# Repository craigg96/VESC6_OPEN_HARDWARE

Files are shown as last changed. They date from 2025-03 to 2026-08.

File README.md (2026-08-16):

# VESC6_OPEN_HARDWARE
Open source implementation of the vesc 6 hardware schematics published by Benjamin Vedder. Built in KiCAD and contains JLCPCB component IDs for everthing populated on the board so anyone can order their own!

## Design
* Continuous current: 70A; instantaneous current: 120A (With proper heat sinking)
* STL130N6F7 MOSFETs rated to switch up to 130A, software limits it to 120A.
* Voltage: 10V-60V(Cells: 3-13S)
* Ports: USB, CAN x2, ADC, on/off switch, SWD, Hall Sensors
* LSM6DS3 IMU
* JST-SH connectors (6pin and 4 pin)
* Holes either side of the MOSFETs allow for even clamping of a simple rectangular heatsink.

## Manufacture
* Economy PCBA maufacture can be used without placing the IMU - 5 boards approx £160GBP
* Standard PCBA manufacture with placing the IMU costs more - 5 boards approx £200GBP
* Custom board software build as well as hardware configuration files are available in the software folder.

## Testing so far...
Release 1 has been flashed and fully tested on the bench to verify current feedback, backEMF sensing, temperature sensing and IMU work as expected.
Hardware has been field tested by several months of daily use (ebike) pulling sustained power over 2kW with no issues.

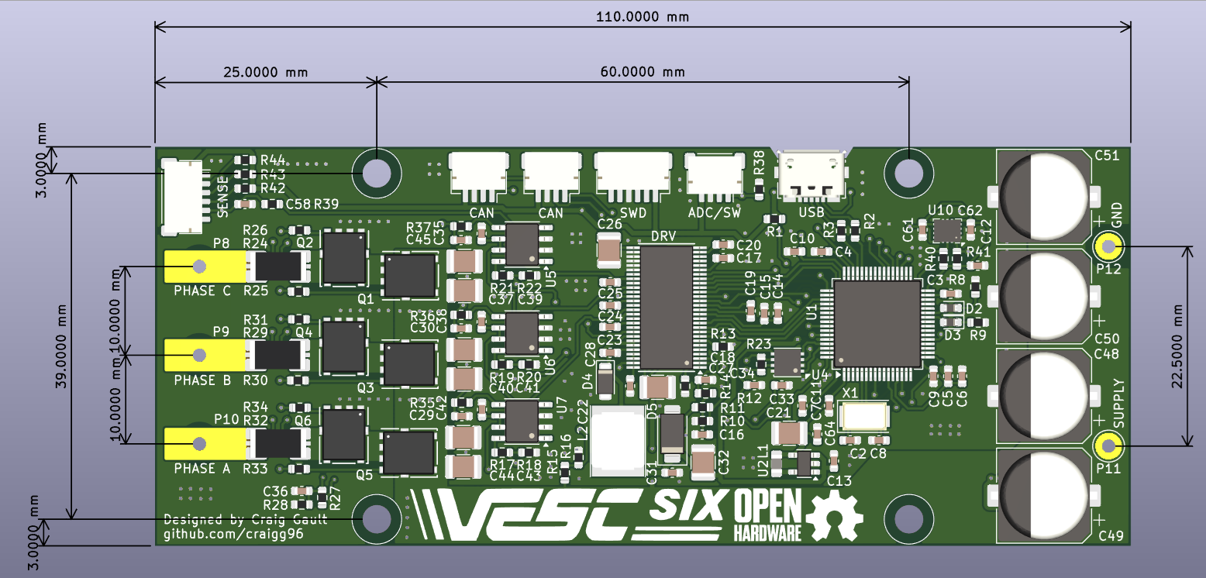
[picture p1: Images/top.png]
top

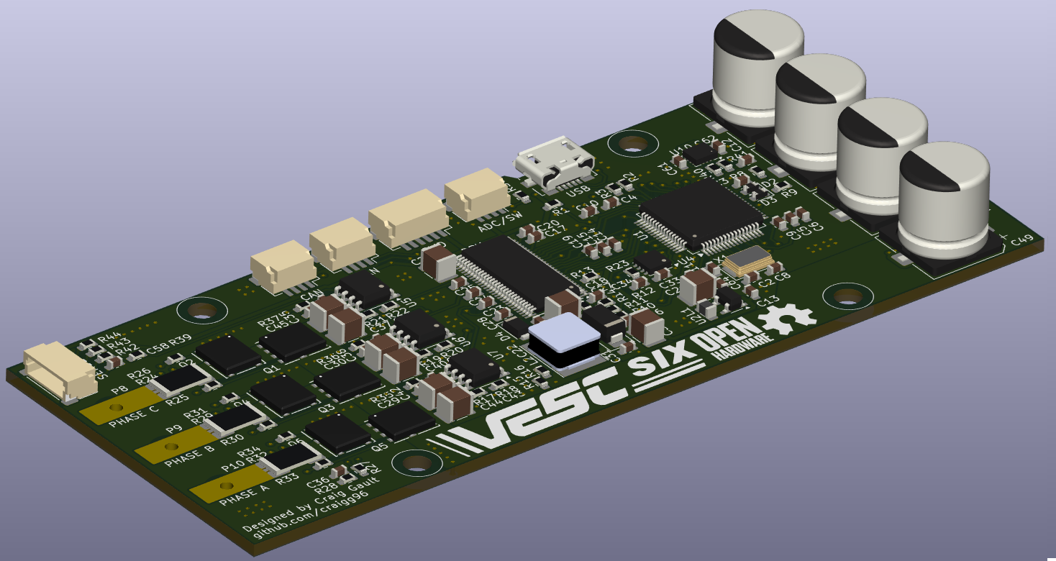
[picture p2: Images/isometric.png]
isometric

isometric

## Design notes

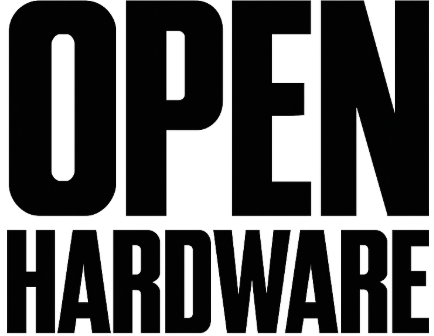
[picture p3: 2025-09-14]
Images/OH TEXT.png

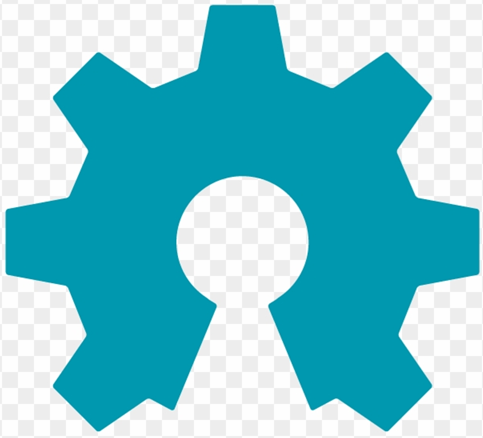
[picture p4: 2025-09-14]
Images/OH.png

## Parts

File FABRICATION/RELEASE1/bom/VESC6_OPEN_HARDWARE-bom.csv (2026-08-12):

Designator | JLCPCB Part # | Qty | Value
C2,C8 | C1644 | 2 | 15p
C3,C4,C5,C6,C9,C10,C11,C12,C13,C14,C15,C17,C20,C31,C33,C34,C35,C36,C38,C42,C64 | C23630 | 21 | 2.2uF
C7,C28,C58,C61,C62 | C14663 | 5 | 100n
C16 | C1631 | 1 | 6.8n
C18 | C107035 | 1 | 120p
C19 | C21122 | 1 | 22n
C21,C32 | C16133 | 2 | 100u
C22 | C1596 | 1 | 15n
C23,C24,C25 | C21120 | 3 | 220n
C26,C27,C37,C39,C40,C41,C43,C44 | C385987 | 8 | 4.7u_100v
C29,C30,C45 | C53987 | 3 | 4.7n
C48,C49,C50,C51 | C7471900 | 4 | 220u_63v
D2 | C2286 | 1 | RED
D3 | C2290 | 1 | WHITE
D4 | C2923951 | 1 | DIODE
D5 | C129544 | 1 | TVS 5V
H1,H2,H3,H4 |  | 4 | MountingHole
L1 | C383398 | 1 | 2.2u
L2 | C266430 | 1 | 22u
P1 | C132560 | 1 | USB_OTG
P2,P5,P6 | C23390337 | 1 | 4PINCONN
P3,P4 | C160405 | 1 | 6PINCONN
P8 |  | 1 | PH_C
P9 |  | 1 | PH_B
P10 |  | 1 | PH_A
P11 |  | 1 | SUPPLY
P12 |  | 1 | GND
Q1,Q2,Q3,Q4,Q5,Q6 | C501008 | 6 | STL130N6F7
R1,R38 |  | 1 | DNP
R2,R3 | C23345 | 2 | 22R
R8,R9,R23 | C22787 | 3 | 120R
R10 | C22978 | 1 | 3.3k
R11 | C25810 | 1 | 18k
R12 | C22809 | 1 | 15k
R13,R28,R39 | C25804 | 4 | 10k
R14 | C22961 | 1 | 220k
R15,R17,R19,R21 | C23153 | 4 | 39k
R16,R18,R20,R22,R42,R43,R44 | C4190 | 7 | 2k2
R24,R29,R32 | C469426 | 3 | 0.0005R
R25,R26,R30,R31,R33,R34 | C23164 | 6 | 4.7R
R27 | C76589 | 1 | NTC 10k
R35,R36,R37 | C22775 | 3 | 100R
R40,R41 | C21190 | 2 | 1k
U1 | C15742 | 1 | STM32F40X_LQFP64
U2 | C477918 | 1 | LM3671
U3 | C98969 | 1 | DRV8301
U4 | C124020 | 1 | TJA1051TK-3
U5,U6,U7 | C495342 | 3 | AD8418
U10 | C967633 | 1 | LSM6DS3TR-C
X1 | C115962 | 1 | 8m

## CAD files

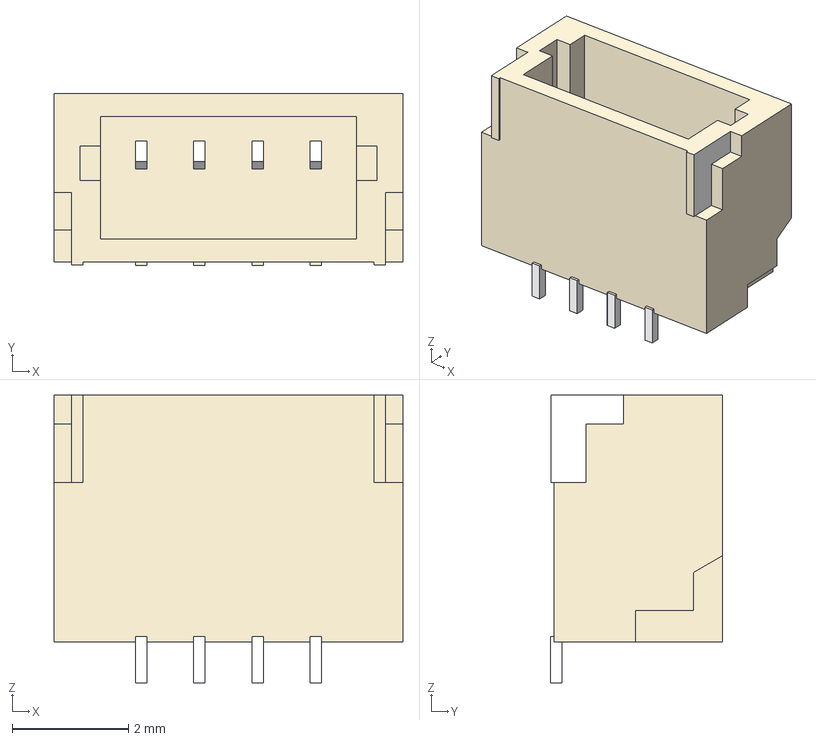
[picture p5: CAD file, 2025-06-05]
3D/SM04B-SRSS-TB.STEP
6.00 x 2.96 x 4.95 mm

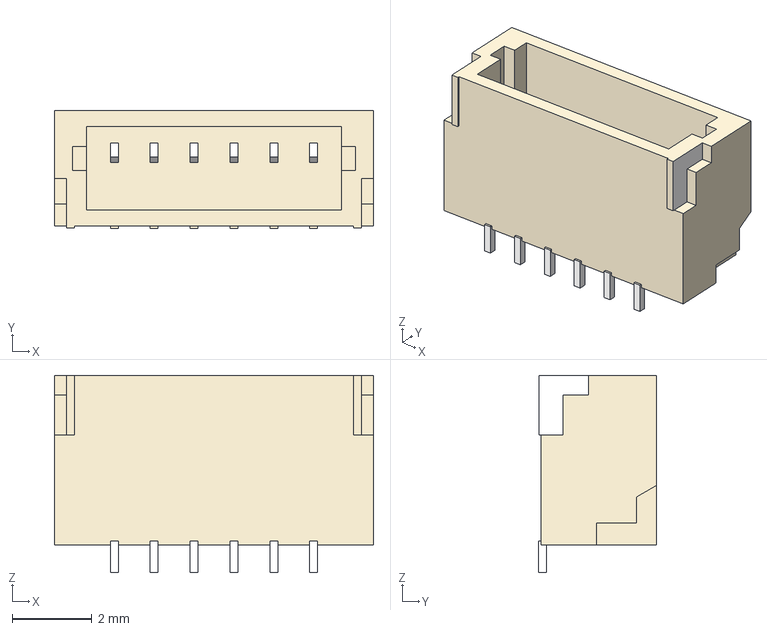
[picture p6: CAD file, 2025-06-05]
3D/SM06B-SRSS-TB.STEP
8.00 x 2.96 x 4.95 mm

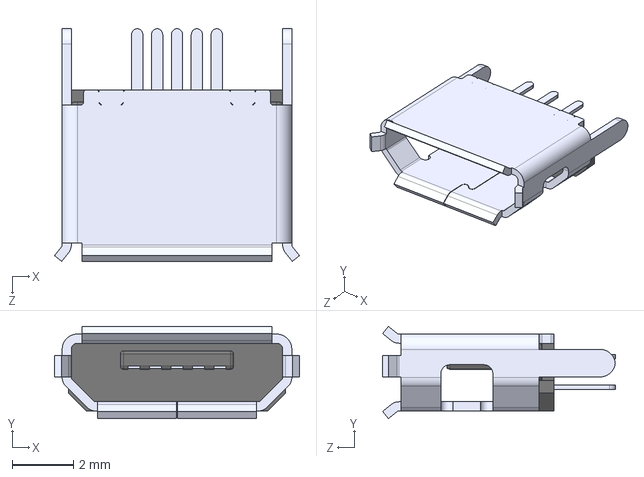
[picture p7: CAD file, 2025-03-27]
3D/USB-F.STEP
8.00 x 3.01 x 7.60 mm

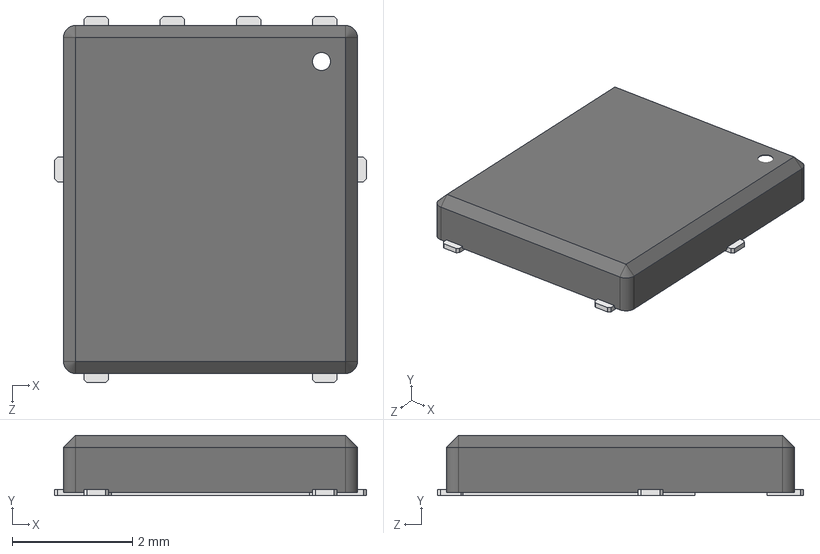
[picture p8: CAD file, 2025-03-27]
3D/SO-8FL.STEP
5.20 x 1.00 x 6.10 mm

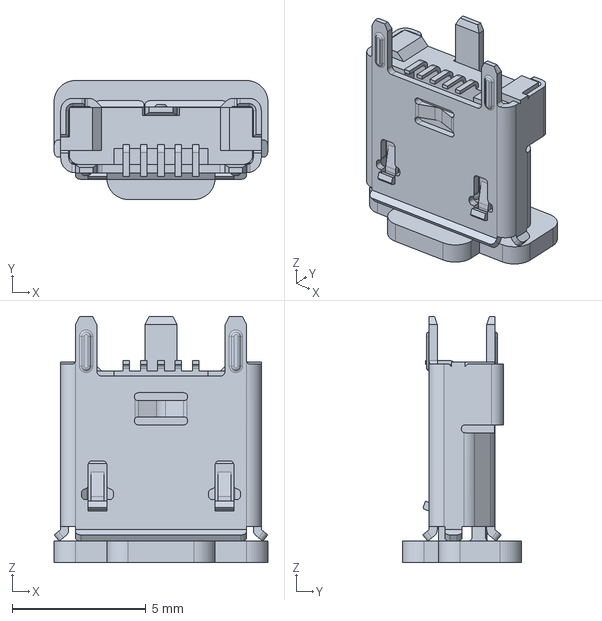
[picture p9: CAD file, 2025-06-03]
3D/1051330001.stp
8.00 x 4.45 x 9.20 mm

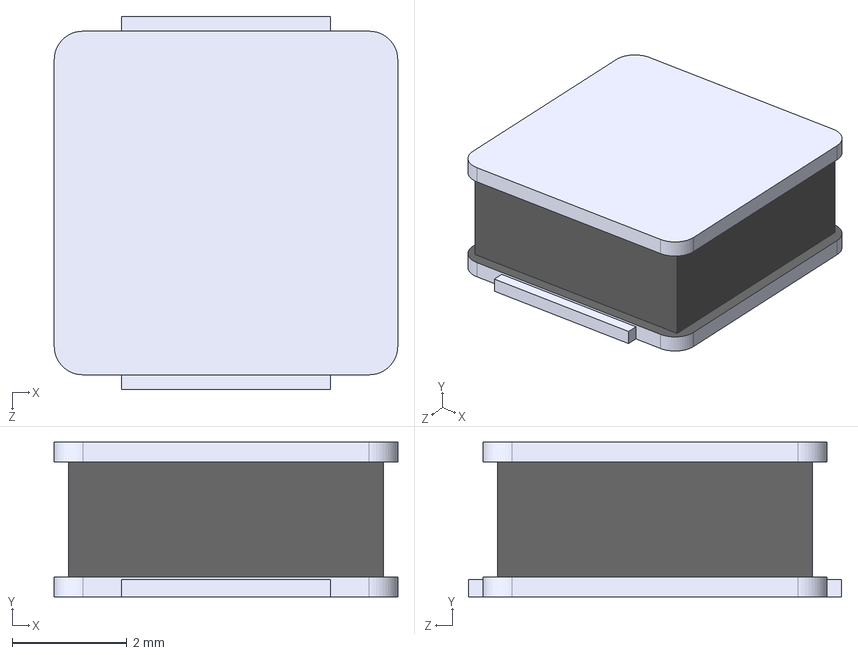
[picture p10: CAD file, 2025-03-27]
3D/C266430_220_inductor.STEP
6.00 x 2.70 x 6.51 mm

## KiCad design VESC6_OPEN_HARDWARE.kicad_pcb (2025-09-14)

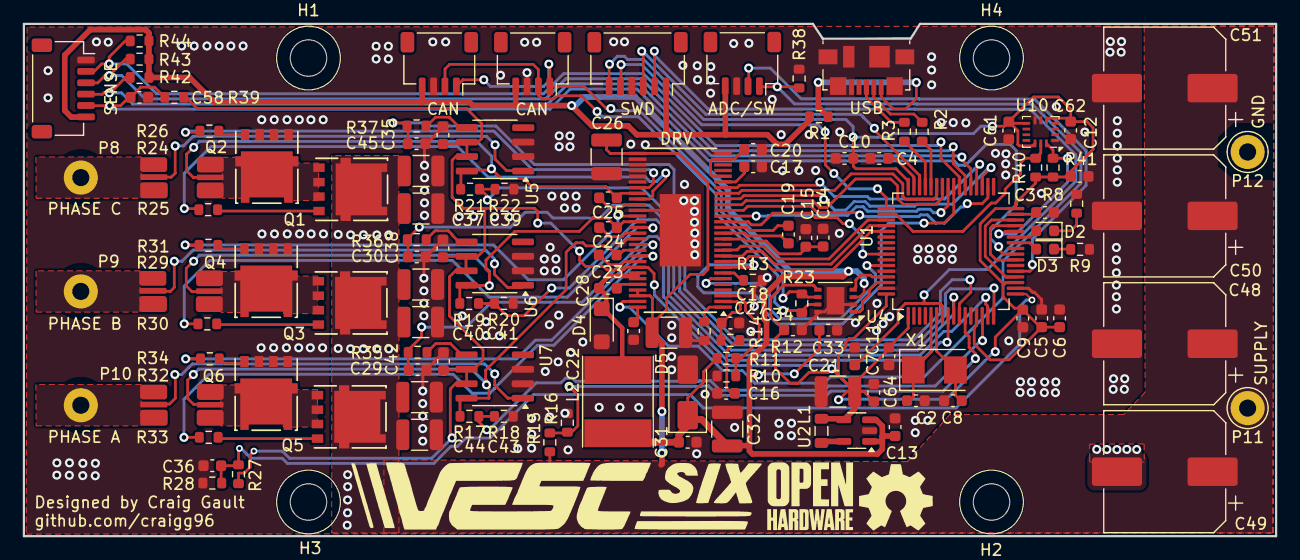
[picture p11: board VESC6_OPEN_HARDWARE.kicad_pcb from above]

Board: 4 copper layers, 110.0 x 45.0 mm, 128 parts (0 on the bottom side), 92 nets.

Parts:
ADC/SW: ADC_SWITCH; JST_SH_SM04B-SRSS-TB_1x04-1MP_P1.00mm_Horizontal
C2, C8: 15p; C_0603_1608Metric
C3, C4, C5, C6, C9, C10, C11, C12, C13, C14, C15, C17, C20, C31, C33, C34, C35, C36, C38, C42, C64: 2.2uF; C_0603_1608Metric
C7, C28, C58, C61, C62: 100n; C_0603_1608Metric
C16: 6.8n; C_0603_1608Metric
C18: 120p; C_0603_1608Metric
C19: 22n; C_0603_1608Metric
C21, C32: 100u; C_1210_3225Metric
C22: 15n; C_0603_1608Metric
C23, C24, C25: 220n; C_0603_1608Metric
C26, C27, C37, C39, C40, C41, C43, C44: 4.7u_100v; C_1210_3225Metric
C29, C30, C45: 4.7n; C_0603_1608Metric
C48, C49, C50, C51: 220u_63v; CP_Elec_10x10.5
CAN: CAN1; JST_SH_SM04B-SRSS-TB_1x04-1MP_P1.00mm_Horizontal
CAN#2: CAN2; JST_SH_SM04B-SRSS-TB_1x04-1MP_P1.00mm_Horizontal
D2: RED; D_0603_1608Metric
D3: WHITE; D_0603_1608Metric
D4: DIODE; D_SMF
D5: TVS 5V; D_SMA
H1, H2, H3, H4: MountingHole; MountingHole_3mm
L1: 2.2u; L_0805_2012Metric
L2: 22u; L_Taiyo-Yuden_NR-60xx_HandSoldering
P8: PH_C; Pin_D1.3mm_L11.0mm_LooseFit
P9: PH_B; Pin_D1.3mm_L11.0mm_LooseFit
P10: PH_A; Pin_D1.3mm_L11.0mm_LooseFit
P11: SUPPLY; Pin_D1.3mm_L11.0mm_LooseFit
P12: GND; Pin_D1.3mm_L11.0mm_LooseFit
Q1, Q2, Q3, Q4, Q5, Q6: STL130N6F7; NVMFS5C612NL
R1: DNP; R_0603_1608Metric
R2, R3: 22R; R_0603_1608Metric
R8, R9, R23: 120R; R_0603_1608Metric
R10: 3.3k; R_0603_1608Metric
R11: 18k; R_0603_1608Metric
R12: 15k; R_0603_1608Metric
R13, R28, R38, R39: 10k; R_0603_1608Metric
R14: 220k; R_0603_1608Metric
R15, R17, R19, R21: 39k; R_0603_1608Metric
R16, R18, R20, R22, R42, R43, R44: 2k2; R_0603_1608Metric
R24, R29, R32: 0.0005R; 2512_SHUNT
R25, R26, R30, R31, R33, R34: 4.7R; R_0603_1608Metric
R27: NTC 10k; R_0603_1608Metric
R35, R36, R37: 100R; R_0603_1608Metric
R40, R41: 1k; R_0603_1608Metric
SENSE: HALL/Encoder; JST_SH_SM06B-SRSS-TB_1x06-1MP_P1.00mm_Horizontal
SWD: SWD; JST_SH_SM06B-SRSS-TB_1x06-1MP_P1.00mm_Horizontal
U1: STM32F40X_LQFP64; LQFP-64_10x10mm_P0.5mm
U2: LM3671; SOT-23-5
U3: DRV8301; HTSSOP-56-1EP_6.1x14mm_P0.5mm_EP3.61x6.35mm
U4: TJA1051TK-3; DFN-8-1EP_3x3mm_P0.65mm_EP1.55x2.4mm
U5, U6, U7: AD8418; SOIC-8_3.9x4.9mm_P1.27mm
U10: LSM6DS3TR-C; Bosch_LGA-14_3x2.5mm_P0.5mm
USB: USB_OTG; USB_Micro-B_Molex_47346-0001
X1: 8m; Crystal_SMD_5032-2Pin_5.0x3.2mm

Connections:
+5V: ADC/SW.4, C13.1, C31.1, C32.1, C33.1, CAN.4, CAN#2.4, D5.1 (K), L2.2, R1.1, R11.2, R42.2, R43.2, R44.2, SENSE.6, SWD.1, U2.1 (Vin), U2.3 (EN), U4.3 (VCC)
/CAN/CANH: CAN.2, CAN#2.2, R23.1, U4.7 (CANH)
/CAN/CANL: CAN.1, CAN#2.1, R23.2, U4.6 (CANL)
/CAN/RX: U1.61 (PB8), U4.4 (RXD)
/CAN/TX: U1.62 (PB9), U4.1 (TXD)
/DRV8301/CS: U1.40 (PC9), U3.8 (M_PWM)
/DRV8301/EN_GATE: U1.57 (PB5), U3.16 (EN_GATE)
/DRV8301/FAULT: U1.59 (PB7), U3.6 (FAULT)
/DRV8301/GH_A: R33.2, U3.47 (GH_A)
/DRV8301/GH_B: R30.2, U3.42 (GH_B)
/DRV8301/GH_C: R25.2, U3.37 (GH_C)
/DRV8301/GL_A: R34.2, U3.45 (GL_A)
/DRV8301/GL_B: R31.2, U3.40 (GL_B)
/DRV8301/GL_C: R26.2, U3.35 (GL_C)
/DRV8301/INH_A: U1.41 (PA8), U3.17 (INH_A)
/DRV8301/INH_B: U1.42 (PA9(OTG_FS_VBUS)), U3.19 (INH_B)
/DRV8301/INH_C: U1.43 (PA10), U3.21 (INH_C)
/DRV8301/INL_A: U1.34 (PB13(OTG_HS_VBUS)), U3.18 (INL_A)
/DRV8301/INL_B: U1.35 (PB14), U3.20 (INL_B)
/DRV8301/INL_C: U1.36 (PB15), U3.22 (INL_C)
/DRV8301/SCLK: U1.51 (PC10), U3.11 (OC_ADJ)
/DRV8301/SDI: U1.53 (PC12), U3.9 (M_OC)
/DRV8301/SDO: U1.52 (PC11), U3.10 (GAIN)
/DRV8301/SENS_A: R17.2, R18.2, U1.14 (PA0(ADC123_IN0/WKUP))
/DRV8301/SENS_B: R19.2, R20.2, U1.15 (PA1(ADC123_IN1))
/DRV8301/SENS_C: R21.2, R22.2, U1.16 (PA2(ADC123_IN2))
/DRV8301/SENS_SUPPLY: R15.2, R16.2, U1.11 (PC3(ADC123_IN13))
/DRV8301/SH_A: C23.1, Q5.3 (S), Q6.1 (D), R17.1, R32.1, U3.46 (SH_A), U7.8 (IN+)
/DRV8301/SH_B: C24.1, Q3.3 (S), Q4.1 (D), R19.1, R29.1, U3.41 (SH_B), U6.8 (IN+)
/DRV8301/SH_C: C25.1, Q1.3 (S), Q2.1 (D), R21.1, R24.1, U3.36 (SH_C), U5.8 (IN+)
/DRV8301/SWITCH-: ADC/SW.1, R38.1, U3.55 (EN_BUCK)
/IMU/SCL: R40.2, U1.50 (PA15(JTDI)), U10.13 (SCX)
/IMU/SDA: R41.1, U1.28 (PB2-BOOT1), U10.14 (SDX)
/power/CURR_A: C29.1, R35.2, U1.8 (PC0(ADC123_IN10))
/power/CURR_B: C30.1, R36.2, U1.9 (PC1(ADC123_IN11))
/power/CURR_C: C45.1, R37.2, U1.10 (PC2(ADC123_IN12))
/power/C_A: R35.1, U7.5 (OUT)
/power/C_B: R36.1, U6.5 (OUT)
/power/C_C: R37.1, U5.5 (OUT)
/power/TEMP: C36.1, R27.2, R28.1, U1.17 (PA3(ADC123_IN3))
/stm32f40x/HALL_1: R42.1, SENSE.4, U1.37 (PC6)
/stm32f40x/HALL_2: R43.1, SENSE.3, U1.38 (PC7)
/stm32f40x/HALL_3: R44.1, SENSE.2, U1.39 (PC8)
/stm32f40x/LED_GREEN: D3.2 (A), U1.26 (PB0(ADC12_IN8))
/stm32f40x/LED_RED: D2.2 (A), U1.27 (PB1(ADC12_IN9))
/stm32f40x/NRST: C7.1, SWD.2, U1.7 (NRST)
/stm32f40x/RX_SDA_NSS: U1.20 (PA4(ADC12_IN4/DAC1_OUT)), U1.30 (PB11)
/stm32f40x/SCK_ADC_EXT: ADC/SW.2, U1.21 (PA5(ADC12_IN5/DAC2_OUT))
/stm32f40x/SWCLK: SWD.5, U1.49 (PA14(JTCK-SWCLK))
/stm32f40x/SWDIO: SWD.3, U1.46 (PA13(JTMS-SWDIO))
/stm32f40x/TEMP_MOTOR: C58.2, R39.2, SENSE.5, U1.24 (PC4(ADC12_IN14))
/stm32f40x/TX_SCL_MOSI: U1.23 (PA7(ADC12_IN7)), U1.29 (PB10)
/stm32f40x/USB_DM: R2.1, U1.44 (PA11)
/stm32f40x/USB_DP: R3.1, U1.45 (PA12)
GND: ADC/SW.3, C2.1, C3.1, C4.1, C5.2, C6.2, C7.2, C8.1, C9.2, C10.2, C11.2, C12.2, C13.2, C14.2, C15.2, C16.1, C17.2, C18.1, C20.2, C21.2, C22.2, C26.2, C27.2, C29.2, C30.2, C31.2, C32.2, C33.2, C34.2, C35.2, C36.2, C37.2, C38.2, C39.2, C40.2, C41.2, C42.2, C43.2, C44.2, C45.2, C48.2, C49.2, C50.2, C51.2, C58.1, C61.1, C62.1, C64.2, CAN.3, CAN#2.3, D4.2 (A), D5.2 (A), P12.1, Q2.3 (S), Q4.3 (S), Q6.3 (S), R8.2, R9.2, R10.1, R13.2, R14.1, R16.1, R18.1, R20.1, R22.1, R28.2, R38.2, SENSE.1, SWD.4, U1.12 (VSSA), U1.18 (VSS), U1.60 (BOOT0(VPP)), U1.63 (VSS), U2.2 (GND), U3.28 (AGND), U3.30 (SP2), U3.31 (SN2), U3.32 (SP1), U3.33 (SN1), U3.34 (SL_C), U3.39 (SL_B), U3.44 (SL_A), U3.57 (GND(POWER_PAD)), U4.2 (GND), U4.8 (S), U4.9 (GND), U5.2 (GND), U5.3 (REF2), U6.2 (GND), U6.3 (REF2), U7.2 (GND), U7.3 (REF2), U10.1 (SDO), U10.6 (GNDIO), U10.7 (GND), USB.5 (GND), USB.6 (Shield)
unnamed: C16.2, R12.1
unnamed: D2.1 (K), R8.1
unnamed: D3.1 (K), R9.1
unnamed: C28.1, D4.1 (K), L2.1, U3.50 (PH), U3.51 (PH)
unnamed: R3.2, USB.3 (D+)
unnamed: R2.2, USB.2 (D-)
unnamed: R1.2, USB.1 (VBUS)
unnamed: P8.1, R24.2, U5.1 (IN-)
unnamed: P9.1, R29.2, U6.1 (IN-)
unnamed: P10.1, R32.2, U7.1 (IN-)
unnamed: Q1.2 (G), R25.1
unnamed: Q2.2 (G), R26.1
unnamed: Q3.2 (G), R30.1
unnamed: Q4.2 (G), R31.1
unnamed: Q5.2 (G), R33.1
unnamed: Q6.2 (G), R34.1
unnamed: C2.2, U1.5 (PH0-OSC_IN), X1.1
unnamed: C8.2, U1.6 (PH1-OSC_OUT), X1.2
unnamed: C3.2, U1.31 (VCAP1)
unnamed: C4.2, U1.47 (VCAP2)
unnamed: L1.1, U2.5 (SW)
unnamed: C20.1, U3.24 (REF), U3.27 (AVDD)
unnamed: C23.2, U3.48 (BST_A)
unnamed: C24.2, U3.43 (BST_B)
unnamed: C28.2, U3.52 (BST_BK)
unnamed: C25.2, U3.38 (BST_C)
unnamed: C18.2, R12.2, U3.2 (COMP)
unnamed: C19.1, U3.14 (CP1)
unnamed: C19.2, U3.15 (CP2)
unnamed: R13.1, U3.7 (DTC)
unnamed: C17.1, U3.23 (DVDD)
unnamed: C14.1, C15.1, U3.13 (GVDD)
unnamed: R14.2, U3.1 (RT_CLK)
unnamed: C22.1, U3.56 (SS_TR)
unnamed: R10.2, R11.1, U3.3 (VSENSE)
SUPPLY: C26.1, C27.1, C37.1, C39.1, C40.1, C41.1, C43.1, C44.1, C48.1, C49.1, C50.1, C51.1, P11.1, Q1.1 (D), Q3.1 (D), Q5.1 (D), R15.1, U3.29 (PVDD1), U3.53 (PVDD2), U3.54 (PVDD2)
VCC: C5.1, C6.1, C9.1, C10.1, C11.1, C12.1, C21.1, C34.1, C35.1, C38.1, C42.1, C61.2, C62.2, C64.1, L1.2, R27.1, R39.1, R40.1, R41.2, SWD.6, U1.1 (VBAT), U1.13 (VDDA), U1.19 (VDD), U1.32 (VDD), U1.48 (VDD), U1.64 (VDD), U2.4 (FB), U3.49 (BIAS), U4.5 (VIO), U5.6 (VS), U5.7 (REF1), U6.6 (VS), U6.7 (REF1), U7.6 (VS), U7.7 (REF1), U10.5 (VDDIO), U10.8 (VDD), U10.12 (CSB)

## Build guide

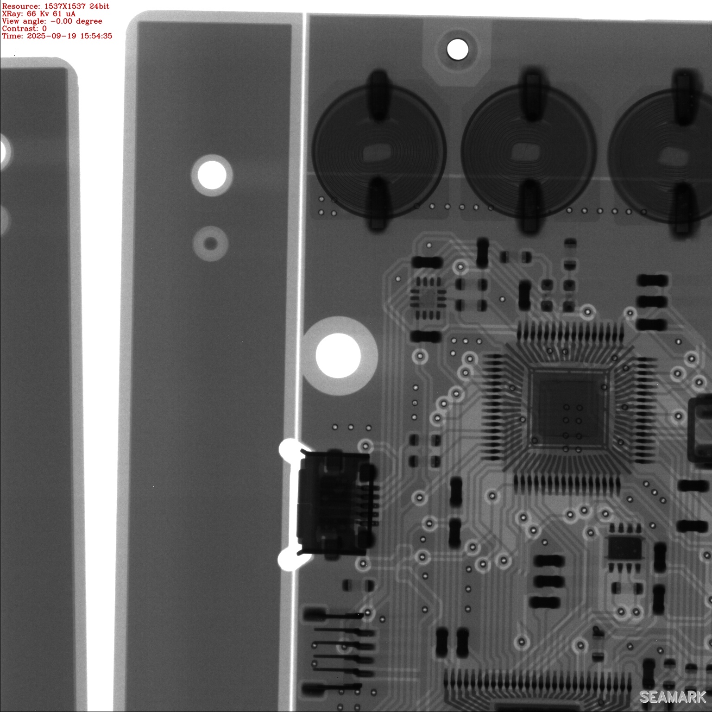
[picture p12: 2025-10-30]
FABRICATION/RELEASE1/x-ray inspection/4.jpg

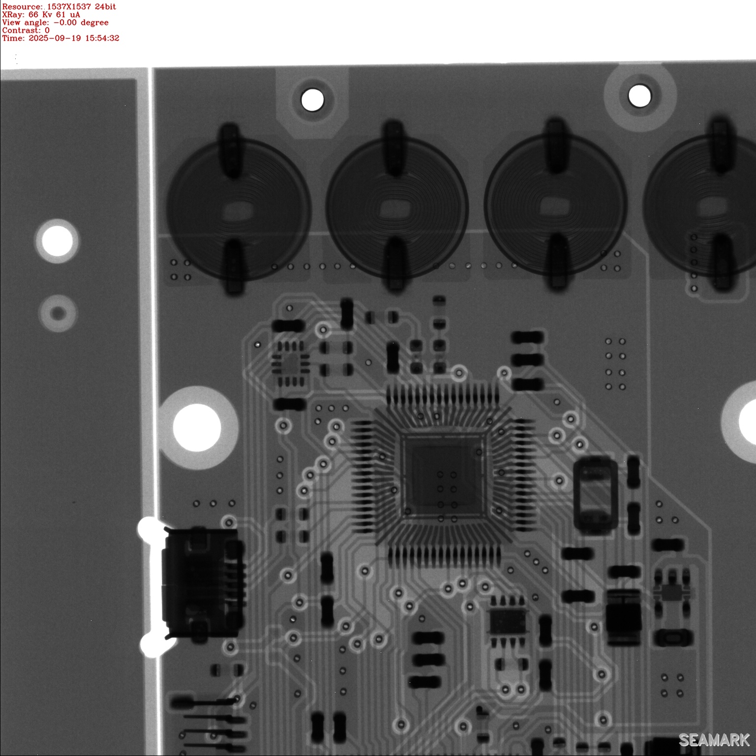
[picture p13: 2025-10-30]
FABRICATION/RELEASE1/x-ray inspection/3.jpg

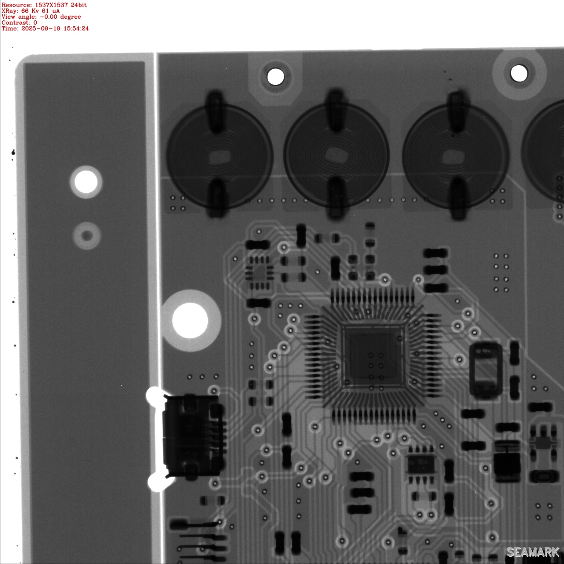
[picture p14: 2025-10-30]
FABRICATION/RELEASE1/x-ray inspection/1.jpg

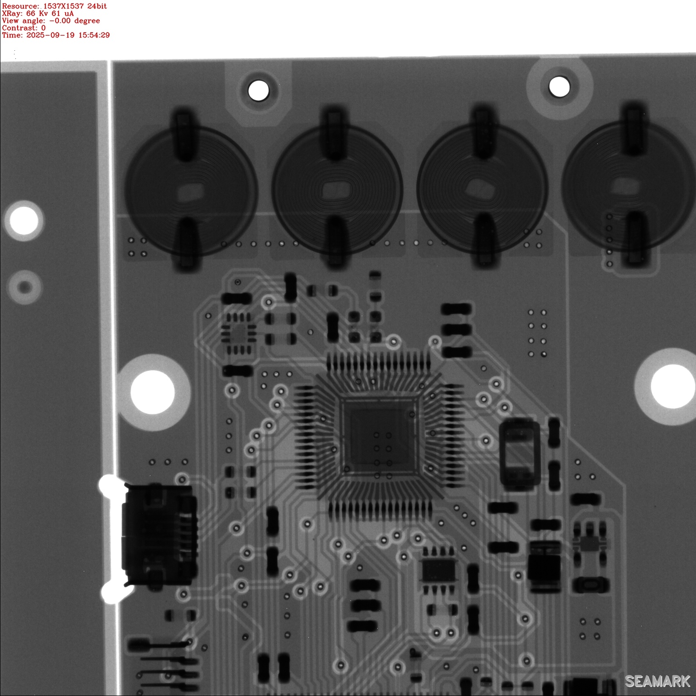
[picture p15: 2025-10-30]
FABRICATION/RELEASE1/x-ray inspection/2.jpg

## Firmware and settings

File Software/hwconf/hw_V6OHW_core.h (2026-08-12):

/*
	Copyright 2016 - 2026 Benjamin Vedder	benjamin@vedder.se

	This file is part of the VESC firmware.

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
    You should have received a copy of the GNU General Public License
    along with this program.  If not, see <http://www.gnu.org/licenses/>.
    */

#ifndef HW_V6OHW_CORE_H_
#define HW_V6OHW_CORE_H_

#ifdef HW_V6OHW_IS_MK1
#define HW_NAME                 "V6OHW"
#else
#error "Must include hardware type"
#endif

#define HW_MAJOR                1
#define HW_MINOR                0

// HW properties
#define HW_HAS_DRV8301
#define HW_HAS_3_SHUNTS
#define HW_HAS_PHASE_SHUNTS
#define HW_HAS_PERMANENT_NRF

// Macros
#define ENABLE_GATE()          palSetPad(GPIOB, 5)
#define DISABLE_GATE()         palClearPad(GPIOB, 5)
#define DCCAL_ON()
#define DCCAL_OFF()
#define IS_DRV_FAULT()         (!palReadPad(GPIOB, 7))

#define LED_GREEN_ON()         palSetPad(GPIOB, 0)
#define LED_GREEN_OFF()        palClearPad(GPIOB, 0)
#define LED_RED_ON()           palSetPad(GPIOB, 1)
#define LED_RED_OFF()          palClearPad(GPIOB, 1)

#define CURRENT_FILTER_ON()    palSetPad(GPIOD, 2)
#define CURRENT_FILTER_OFF()   palClearPad(GPIOD, 2)

// Component parameters
#ifndef V_REG
#define V_REG                  3.3
#endif
#ifndef VIN_R1
#define VIN_R1                 39000.0
#endif
#ifndef VIN_R2
#define VIN_R2                 2200.0
#endif
#ifndef CURRENT_AMP_GAIN
#define CURRENT_AMP_GAIN       20.0
#endif
#ifndef CURRENT_SHUNT_RES
#define CURRENT_SHUNT_RES      0.0005
#endif

// Voltage and temperature macros
#define GET_INPUT_VOLTAGE()    ((V_REG / 4095.0) * (float)ADC_Value[ADC_IND_VIN_SENS] * ((VIN_R1 + VIN_R2) / VIN_R2))
#define NTC_RES(adc_val)       ((4095.0 * 10000.0) / adc_val - 10000.0)
#define NTC_TEMP(adc_ind)      (1.0 / ((logf(NTC_RES(ADC_Value[adc_ind]) / 10000.0) / 3380.0) + (1.0 / 298.15)) - 273.15)
#define NTC_RES_MOTOR(adc_val) (10000.0 / ((4095.0 / (float)adc_val) - 1.0))
#define NTC_TEMP_MOTOR(beta)   (1.0 / ((logf(NTC_RES_MOTOR(ADC_Value[ADC_IND_TEMP_MOTOR]) / 10000.0) / beta) + (1.0 / 298.15)) - 273.15)
#define ADC_VOLTS(ch)          ((float)ADC_Value[ch] / 4096.0 * V_REG)

// Double samples configuration
#ifndef CURR1_DOUBLE_SAMPLE
#define CURR1_DOUBLE_SAMPLE    0
#endif
#ifndef CURR2_DOUBLE_SAMPLE
#define CURR2_DOUBLE_SAMPLE    0
#endif
#ifndef CURR3_DOUBLE_SAMPLE
#define CURR3_DOUBLE_SAMPLE    0
#endif

// ADC Vector
#define HW_ADC_INJ_CHANNELS    3
#define HW_ADC_NBR_CONV        5
#define HW_ADC_CHANNELS        (HW_ADC_NBR_CONV * 3)

// ADC Indexes
#define ADC_IND_SENS1          3
#define ADC_IND_SENS2          4
#define ADC_IND_SENS3          5
#define ADC_IND_CURR1          0
#define ADC_IND_CURR2          1
#define ADC_IND_CURR3          2
#define ADC_IND_VIN_SENS       11
#define ADC_IND_EXT            6
#define ADC_IND_EXT2           7
#define ADC_IND_TEMP_MOS       8
#define ADC_IND_TEMP_MOTOR     9
#define ADC_IND_VREFINT        12

// COMM-port ADC GPIOs
#define HW_ADC_EXT_GPIO        GPIOA
#define HW_ADC_EXT_PIN         5
#define HW_ADC_EXT2_GPIO       GPIOA
#define HW_ADC_EXT2_PIN        6

// UART Peripheral
#define HW_UART_DEV            SD3
#define HW_UART_GPIO_AF        GPIO_AF_USART3
#define HW_UART_TX_PORT        GPIOB
#define HW_UART_TX_PIN         10
#define HW_UART_RX_PORT        GPIOB
#define HW_UART_RX_PIN         11

// ICU Peripheral for servo decoding
#define HW_USE_SERVO_TIM4
#define HW_ICU_TIMER           TIM4
#define HW_ICU_TIM_CLK_EN()    RCC_APB1PeriphClockCmd(RCC_APB1Periph_TIM4, ENABLE)
#define HW_ICU_DEV             ICUD4
#define HW_ICU_CHANNEL         ICU_CHANNEL_1
#define HW_ICU_GPIO_AF         GPIO_AF_TIM4
#define HW_ICU_GPIO            GPIOB
#define HW_ICU_PIN             6

// I2C Peripheral
#define HW_I2C_DEV             I2CD2
#define HW_I2C_GPIO_AF         GPIO_AF_I2C2
#define HW_I2C_SCL_PORT        GPIOB
#define HW_I2C_SCL_PIN         10
#define HW_I2C_SDA_PORT        GPIOB
#define HW_I2C_SDA_PIN         11

// Hall/encoder pins
#define HW_HALL_ENC_GPIO1      GPIOC
#define HW_HALL_ENC_PIN1       6
#define HW_HALL_ENC_GPIO2      GPIOC
#define HW_HALL_ENC_PIN2       7
#define HW_HALL_ENC_GPIO3      GPIOC
#define HW_HALL_ENC_PIN3       8
#define HW_ENC_TIM             TIM3
#define HW_ENC_TIM_AF          GPIO_AF_TIM3
#define HW_ENC_TIM_CLK_EN()    RCC_APB1PeriphClockCmd(RCC_APB1Periph_TIM3, ENABLE)
#define HW_ENC_EXTI_PORTSRC    EXTI_PortSourceGPIOC
#define HW_ENC_EXTI_PINSRC     EXTI_PinSource8
#define HW_ENC_EXTI_CH         EXTI9_5_IRQn
#define HW_ENC_EXTI_LINE       EXTI_Line8
#define HW_ENC_EXTI_ISR_VEC    EXTI9_5_IRQHandler
#define HW_ENC_TIM_ISR_CH      TIM3_IRQn
#define HW_ENC_TIM_ISR_VEC     TIM3_IRQHandler

// SPI pins
#define HW_SPI_DEV             SPID1
#define HW_SPI_GPIO_AF         GPIO_AF_SPI1
#define HW_SPI_PORT_NSS        GPIOA
#define HW_SPI_PIN_NSS         4
#define HW_SPI_PORT_SCK        GPIOA
#define HW_SPI_PIN_SCK         5
#define HW_SPI_PORT_MOSI       GPIOA
#define HW_SPI_PIN_MOSI        7
#define HW_SPI_PORT_MISO       GPIOA
#define HW_SPI_PIN_MISO        6

// SPI for DRV8301
#define DRV8301_MOSI_GPIO      GPIOC
#define DRV8301_MOSI_PIN       12
#define DRV8301_MISO_GPIO      GPIOC
#define DRV8301_MISO_PIN       11
#define DRV8301_SCK_GPIO       GPIOC
#define DRV8301_SCK_PIN        10
#define DRV8301_CS_GPIO        GPIOC
#define DRV8301_CS_PIN         9

// IMU LSM6DS3
#define LSM6DS3_SDA_GPIO       GPIOB
#define LSM6DS3_SDA_PIN        2
#define LSM6DS3_SCL_GPIO       GPIOA
#define LSM6DS3_SCL_PIN        15

// Measurement macros
#define ADC_V_L1               ADC_Value[ADC_IND_SENS1]
#define ADC_V_L2               ADC_Value[ADC_IND_SENS2]
#define ADC_V_L3               ADC_Value[ADC_IND_SENS3]
#define ADC_V_ZERO             (ADC_Value[ADC_IND_VIN_SENS] / 2)

// Hall reading macros
#define READ_HALL1()           palReadPad(HW_HALL_ENC_GPIO1, HW_HALL_ENC_PIN1)
#define READ_HALL2()           palReadPad(HW_HALL_ENC_GPIO2, HW_HALL_ENC_PIN2)
#define READ_HALL3()           palReadPad(HW_HALL_ENC_GPIO3, HW_HALL_ENC_PIN3)

// Default setting overrides
#ifndef MCCONF_DEFAULT_MOTOR_TYPE
#define MCCONF_DEFAULT_MOTOR_TYPE    MOTOR_TYPE_FOC
#endif
#ifndef MCCONF_FOC_F_ZV
#define MCCONF_FOC_F_ZV              30000.0
#endif
#ifndef MCCONF_L_MAX_ABS_CURRENT
#define MCCONF_L_MAX_ABS_CURRENT     150.0
#endif
#ifndef MCCONF_FOC_SAMPLE_V0_V7
#define MCCONF_FOC_SAMPLE_V0_V7      false
#endif

// Setting limits
#define HW_LIM_CURRENT         -120.0, 120.0
#define HW_LIM_CURRENT_IN      -120.0, 120.0
#define HW_LIM_CURRENT_ABS     0.0, 160.0
#define HW_LIM_VIN             6.0, 57.0
#define HW_LIM_ERPM            -200e3, 200e3
#define HW_LIM_DUTY_MIN        0.0, 0.1
#define HW_LIM_DUTY_MAX        0.0, 0.99
#define HW_LIM_TEMP_FET        -40.0, 110.0

#endif /* HW_V6OHW_CORE_H_ */

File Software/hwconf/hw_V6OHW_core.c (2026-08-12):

/* V6OHW core source */

#include "hw.h"

#include "ch.h"
#include "hal.h"
#include "stm32f4xx_conf.h"
#include "utils_math.h"
#include "drv8301.h"
#include "terminal.h"
#include "commands.h"
#include "mc_interface.h"

// Variables
static volatile bool i2c_running = false;

// I2C configuration
static const I2CConfig i2cfg = {
		OPMODE_I2C,
		100000,
		STD_DUTY_CYCLE
};

void hw_init_gpio(void) {
	// GPIO clock enable
	RCC_AHB1PeriphClockCmd(RCC_AHB1Periph_GPIOA, ENABLE);
	RCC_AHB1PeriphClockCmd(RCC_AHB1Periph_GPIOB, ENABLE);
	RCC_AHB1PeriphClockCmd(RCC_AHB1Periph_GPIOC, ENABLE);
	RCC_AHB1PeriphClockCmd(RCC_AHB1Periph_GPIOD, ENABLE);

	// LEDs
	palSetPadMode(GPIOB, 0,
			PAL_MODE_OUTPUT_PUSHPULL |
			PAL_STM32_OSPEED_HIGHEST);
	palSetPadMode(GPIOB, 1,
			PAL_MODE_OUTPUT_PUSHPULL |
			PAL_STM32_OSPEED_HIGHEST);

	// ENABLE_GATE

	palSetPadMode(GPIOB, 5,
			PAL_MODE_OUTPUT_PUSHPULL |
			PAL_STM32_OSPEED_HIGHEST);

	ENABLE_GATE();

	// Current filter
	palSetPadMode(GPIOD, 2,
			PAL_MODE_OUTPUT_PUSHPULL |
			PAL_STM32_OSPEED_HIGHEST);

	CURRENT_FILTER_OFF();

	// GPIOA Configuration: Channel 1 to 3 as alternate function push-pull
	palSetPadMode(GPIOA, 8, PAL_MODE_ALTERNATE(GPIO_AF_TIM1) |
			PAL_STM32_OSPEED_HIGHEST |
			PAL_STM32_PUDR_FLOATING);
	palSetPadMode(GPIOA, 9, PAL_MODE_ALTERNATE(GPIO_AF_TIM1) |
			PAL_STM32_OSPEED_HIGHEST |
			PAL_STM32_PUDR_FLOATING);
	palSetPadMode(GPIOA, 10, PAL_MODE_ALTERNATE(GPIO_AF_TIM1) |
			PAL_STM32_OSPEED_HIGHEST |
			PAL_STM32_PUDR_FLOATING);

	palSetPadMode(GPIOB, 13, PAL_MODE_ALTERNATE(GPIO_AF_TIM1) |
			PAL_STM32_OSPEED_HIGHEST |
			PAL_STM32_PUDR_FLOATING);
	palSetPadMode(GPIOB, 14, PAL_MODE_ALTERNATE(GPIO_AF_TIM1) |
			PAL_STM32_OSPEED_HIGHEST |
			PAL_STM32_PUDR_FLOATING);
	palSetPadMode(GPIOB, 15, PAL_MODE_ALTERNATE(GPIO_AF_TIM1) |
			PAL_STM32_OSPEED_HIGHEST |
			PAL_STM32_PUDR_FLOATING);

	// Hall sensors
	palSetPadMode(HW_HALL_ENC_GPIO1, HW_HALL_ENC_PIN1, PAL_MODE_INPUT_PULLUP);
	palSetPadMode(HW_HALL_ENC_GPIO2, HW_HALL_ENC_PIN2, PAL_MODE_INPUT_PULLUP);
	palSetPadMode(HW_HALL_ENC_GPIO3, HW_HALL_ENC_PIN3, PAL_MODE_INPUT_PULLUP);

	// Fault pin
	palSetPadMode(GPIOB, 7, PAL_MODE_INPUT_PULLUP);

	// ADC Pins
	palSetPadMode(GPIOA, 0, PAL_MODE_INPUT_ANALOG);
	palSetPadMode(GPIOA, 1, PAL_MODE_INPUT_ANALOG);
	palSetPadMode(GPIOA, 2, PAL_MODE_INPUT_ANALOG);
	palSetPadMode(GPIOA, 3, PAL_MODE_INPUT_ANALOG);
	palSetPadMode(GPIOA, 5, PAL_MODE_INPUT_ANALOG);
	palSetPadMode(GPIOA, 6, PAL_MODE_INPUT_ANALOG);

	palSetPadMode(GPIOC, 0, PAL_MODE_INPUT_ANALOG);
	palSetPadMode(GPIOC, 1, PAL_MODE_INPUT_ANALOG);
	palSetPadMode(GPIOC, 2, PAL_MODE_INPUT_ANALOG);
	palSetPadMode(GPIOC, 3, PAL_MODE_INPUT_ANALOG);
	palSetPadMode(GPIOC, 4, PAL_MODE_INPUT_ANALOG);
	palSetPadMode(GPIOC, 5, PAL_MODE_INPUT_ANALOG);

	drv8301_init();
}

void hw_setup_adc_channels(void) {
	uint8_t t_samp = ADC_SampleTime_15Cycles;

	// ADC1 regular channels
	ADC_RegularChannelConfig(ADC1, ADC_Channel_10, 1, t_samp);
	ADC_RegularChannelConfig(ADC1, ADC_Channel_0, 2, t_samp);
	ADC_RegularChannelConfig(ADC1, ADC_Channel_5, 3, t_samp);
	ADC_RegularChannelConfig(ADC1, ADC_Channel_14, 4, t_samp);
	ADC_RegularChannelConfig(ADC1, ADC_Channel_Vrefint, 5, t_samp);

	// ADC2 regular channels
	ADC_RegularChannelConfig(ADC2, ADC_Channel_11, 1, t_samp);
	ADC_RegularChannelConfig(ADC2, ADC_Channel_1, 2, t_samp);
	ADC_RegularChannelConfig(ADC2, ADC_Channel_6, 3, t_samp);
	ADC_RegularChannelConfig(ADC2, ADC_Channel_15, 4, t_samp);
	ADC_RegularChannelConfig(ADC2, ADC_Channel_0, 5, t_samp);

	// ADC3 regular channels
	ADC_RegularChannelConfig(ADC3, ADC_Channel_12, 1, t_samp);
	ADC_RegularChannelConfig(ADC3, ADC_Channel_2, 2, t_samp);
	ADC_RegularChannelConfig(ADC3, ADC_Channel_3, 3, t_samp);
	ADC_RegularChannelConfig(ADC3, ADC_Channel_13, 4, t_samp);
	ADC_RegularChannelConfig(ADC3, ADC_Channel_1, 5, t_samp);

	// Current oversampling
//	for (int i = 6;i <= 15;i++) {
//		ADC_RegularChannelConfig(ADC1, ADC_Channel_10, i, ADC_SampleTime_56Cycles);
//		ADC_RegularChannelConfig(ADC2, ADC_Channel_11, i, ADC_SampleTime_56Cycles);
//		ADC_RegularChannelConfig(ADC3, ADC_Channel_12, i, ADC_SampleTime_56Cycles);
//	}

	// Injected channels
	ADC_InjectedChannelConfig(ADC1, ADC_Channel_10, 1, t_samp);
	ADC_InjectedChannelConfig(ADC2, ADC_Channel_11, 1, t_samp);
	ADC_InjectedChannelConfig(ADC3, ADC_Channel_12, 1, t_samp);
	ADC_InjectedChannelConfig(ADC1, ADC_Channel_10, 2, t_samp);
	ADC_InjectedChannelConfig(ADC2, ADC_Channel_11, 2, t_samp);
	ADC_InjectedChannelConfig(ADC3, ADC_Channel_12, 2, t_samp);
	ADC_InjectedChannelConfig(ADC1, ADC_Channel_10, 3, t_samp);
	ADC_InjectedChannelConfig(ADC2, ADC_Channel_11, 3, t_samp);
	ADC_InjectedChannelConfig(ADC3, ADC_Channel_12, 3, t_samp);
}

void hw_start_i2c(void) {
	i2cAcquireBus(&HW_I2C_DEV);

	if (!i2c_running) {
		palSetPadMode(HW_I2C_SCL_PORT, HW_I2C_SCL_PIN,
				PAL_MODE_ALTERNATE(HW_I2C_GPIO_AF) |
				PAL_STM32_OTYPE_OPENDRAIN |
				PAL_STM32_OSPEED_MID1 |
				PAL_STM32_PUDR_PULLUP);
		palSetPadMode(HW_I2C_SDA_PORT, HW_I2C_SDA_PIN,
				PAL_MODE_ALTERNATE(HW_I2C_GPIO_AF) |
				PAL_STM32_OTYPE_OPENDRAIN |
				PAL_STM32_OSPEED_MID1 |
				PAL_STM32_PUDR_PULLUP);

		i2cStart(&HW_I2C_DEV, &i2cfg);
		i2c_running = true;
	}

	i2cReleaseBus(&HW_I2C_DEV);
}

void hw_stop_i2c(void) {
	i2cAcquireBus(&HW_I2C_DEV);

	if (i2c_running) {
		palSetPadMode(HW_I2C_SCL_PORT, HW_I2C_SCL_PIN, PAL_MODE_INPUT);
		palSetPadMode(HW_I2C_SDA_PORT, HW_I2C_SDA_PIN, PAL_MODE_INPUT);

		i2cStop(&HW_I2C_DEV);
		i2c_running = false;

	}

	i2cReleaseBus(&HW_I2C_DEV);
}

/**
 * Try to restore the i2c bus
 */
void hw_try_restore_i2c(void) {
	if (i2c_running) {
		i2cAcquireBus(&HW_I2C_DEV);

		palSetPadMode(HW_I2C_SCL_PORT, HW_I2C_SCL_PIN,
				PAL_STM32_OTYPE_OPENDRAIN |
				PAL_STM32_OSPEED_MID1 |
				PAL_STM32_PUDR_PULLUP);

		palSetPadMode(HW_I2C_SDA_PORT, HW_I2C_SDA_PIN,
				PAL_STM32_OTYPE_OPENDRAIN |
				PAL_STM32_OSPEED_MID1 |
				PAL_STM32_PUDR_PULLUP);

		palSetPad(HW_I2C_SCL_PORT, HW_I2C_SCL_PIN);
		palSetPad(HW_I2C_SDA_PORT, HW_I2C_SDA_PIN);

		chThdSleep(1);

		for(int i = 0;i < 16;i++) {
			palClearPad(HW_I2C_SCL_PORT, HW_I2C_SCL_PIN);
			chThdSleep(1);
			palSetPad(HW_I2C_SCL_PORT, HW_I2C_SCL_PIN);
			chThdSleep(1);
		}

		// Generate start then stop condition
		palClearPad(HW_I2C_SDA_PORT, HW_I2C_SDA_PIN);
		chThdSleep(1);
		palClearPad(HW_I2C_SCL_PORT, HW_I2C_SCL_PIN);
		chThdSleep(1);
		palSetPad(HW_I2C_SCL_PORT, HW_I2C_SCL_PIN);
		chThdSleep(1);
		palSetPad(HW_I2C_SDA_PORT, HW_I2C_SDA_PIN);

		palSetPadMode(HW_I2C_SCL_PORT, HW_I2C_SCL_PIN,
				PAL_MODE_ALTERNATE(HW_I2C_GPIO_AF) |
				PAL_STM32_OTYPE_OPENDRAIN |
				PAL_STM32_OSPEED_MID1 |
				PAL_STM32_PUDR_PULLUP);

		palSetPadMode(HW_I2C_SDA_PORT, HW_I2C_SDA_PIN,
				PAL_MODE_ALTERNATE(HW_I2C_GPIO_AF) |
				PAL_STM32_OTYPE_OPENDRAIN |
				PAL_STM32_OSPEED_MID1 |
				PAL_STM32_PUDR_PULLUP);

		HW_I2C_DEV.state = I2C_STOP;
		i2cStart(&HW_I2C_DEV, &i2cfg);

		i2cReleaseBus(&HW_I2C_DEV);
	}
}

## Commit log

2025-03-29 started power stage
    [DRV8301.kicad_sch, VESC6_OPEN_HARDWARE.kicad_pcb, VESC6_OPEN_HARDWARE.kicad_sch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]
2025-03-29 power stage complete
    [VESC6_OPEN_HARDWARE.kicad_pcb]
2025-04-02 DRV8301 Stage Complete
    [VESC6_OPEN_HARDWARE.kicad_pcb]
2025-04-13 Begun wiring main MCU
    [VESC6_OPEN_HARDWARE.kicad_pcb]
2025-05-29 more routing connectors and caps
    [SM04B-SRSS-TB.STEP, SM06B-SRSS-TB.STEP, VESC6_OPEN_HARDWARE.kicad_pcb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]
2025-06-03 More routing, positioning and SMT USB
    [1051330001.stp, VESC6_OPEN_HARDWARE.kicad_pcb, VESC6_OPEN_HARDWARE.kicad_sch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]
2025-06-04 Routing cleanup
    [VESC6_OPEN_HARDWARE.kicad_pcb]
2025-06-05 double CAN ports
    [SM04B-SRSS-TB.STEP, SM06B-SRSS-TB.STEP, VESC6_OPEN_HARDWARE.kicad_pcb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]
2025-06-09 Adjusted connectors and routing
    [VESC6_OPEN_HARDWARE.kicad_pcb, VESC6_OPEN_HARDWARE.kicad_sch, mcu.kicad_sch]
2025-06-10 Board resized and changed usb port
    [VESC6_OPEN_HARDWARE.kicad_pcb, VESC6_OPEN_HARDWARE.kicad_sch, mcu.kicad_sch]
2025-06-11 changed connectors, needs final routing and drc
    [DRV8301.kicad_sch, VESC6_OPEN_HARDWARE.kicad_pcb, VESC6_OPEN_HARDWARE.kicad_sch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]
2025-06-18 Finished routing
    [DRV8301.kicad_sch, VESC6_OPEN_HARDWARE.kicad_pcb, VESC6_OPEN_HARDWARE.kicad_sch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]
2025-06-18 Finished traces, DRC Passed, Grounding needs revised
    [VESC6_OPEN_HARDWARE.kicad_pcb]
2025-06-23 mounting holes, more grounding and routing
    [VESC6_OPEN_HARDWARE.kicad_pcb, VESC6_OPEN_HARDWARE.kicad_sch, mcu.kicad_sch]
2025-09-07 drc clear, added images
    [VESC6_OPEN_HARDWARE.kicad_pcb, mcu.kicad_sch, power.kicad_sch]
2025-10-30 Fix image filename case in README.md
2026-08-12 dont populate R38
    [VESC6_OPEN_HARDWARE-bom.csv]

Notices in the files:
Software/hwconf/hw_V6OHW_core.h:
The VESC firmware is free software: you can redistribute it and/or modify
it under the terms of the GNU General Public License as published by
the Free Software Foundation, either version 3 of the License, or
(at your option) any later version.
